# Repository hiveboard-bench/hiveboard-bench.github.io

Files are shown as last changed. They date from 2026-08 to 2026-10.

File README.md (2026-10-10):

# HiveBoard Website





This repository hosts the official project website for **HiveBoard: An Open, Modular, 3D-Printed Benchmark of Industrial Mechanisms for Robotic and Prosthetic Manipulation**.

**Live Website:** [hiveboard-bench.github.io](https://hiveboard-bench.github.io)  
**Main Project Repository:** [github.com/hiveboard-bench/HiveBoard](https://github.com/hiveboard-bench/HiveBoard)

## Website Purpose

The purpose of this website is to serve as the interactive companion and presentation portal for the HiveBoard benchmark:

- **Interactive 3D & Physics Viewer:** Allows visitors to view and interactively simulate the attachments directly in the browser using [Three.js](https://threejs.org/) and WebAssembly-powered [MuJoCo](https://mujoco.org/).
- **Attachment & Task Catalog:** Details 12 functional 3D-printed attachment designs evaluated in 13 conditions across three manipulation skill categories: *Torque*, *Precision*, and *Composed assembly*.
- **Simulation Compatibility:** Provides information and direct access to digital assets for simulators including MuJoCo, Isaac Sim (USD), and standard URDFs.
- **Experimental Results & Media:** Showcases evaluation results and video demonstrations across diverse robotic embodiments (fixed-base arms, quadruped manipulators, VR-teleoperated robots, and wearable prosthetic hands).
- **Documentation & Evaluation Protocol:** Includes the full HiveBoard documentation, contribution guides, and browser-based 65-trial evaluation runner at [`/hivedocs/`](https://hiveboard-bench.github.io/hivedocs/).

## Tech Stack

- **Bundler / Dev Server:** [Vite](https://vitejs.dev/)
- **UI Framework / Styling:** [Bulma CSS](https://bulma.io/) & Custom CSS
- **3D & Physics Rendering:** [Three.js](https://threejs.org/) & [@mujoco/mujoco](https://www.npmjs.com/package/@mujoco/mujoco)
- **Deployment:** GitHub Pages via `gh-pages`

## Getting Started

### Prerequisites

Make sure you have [Node.js](https://nodejs.org/) (version 18+ recommended) installed.

### Installation

Clone the repository and install the dependencies:

```bash
git clone https://github.com/hiveboard-bench/hiveboard-bench.github.io.git
cd hiveboard-bench.github.io
npm install
```

### Local Development

Start the local Vite development server:

```bash
npm run dev
```

Open your browser at `http://localhost:5173` (or the URL printed in your terminal).

### Build for Production

To create an optimized production build in the `dist/` directory:

```bash
npm run build
```

You can preview the built site locally with:

```bash
npm run preview
```

### Deployment

Deploy to GitHub Pages:

```bash
npm run deploy
```

## Modifying & Authoring Trajectories

The simulation viewer replays deterministic task-space trajectories (approach, grasp, actuate, release, retreat) solved with inverse kinematics and verified against MuJoCo physics. You can modify these trajectories in two ways:

### 1. Interactive Browser-Based Editor

The repository includes a live visual editor to adjust waypoints directly in 3D:

1. **Start the editor backend server:**
   ```bash
   python3 tools/traj_edit.py
   ```
2. **Start the Vite dev server (in a separate terminal):**
   ```bash
   npm run dev
   ```
3. **Open the editor in your browser:**  
   Navigate to `http://localhost:5173/sim/hiveboard-sim.html?edit=1`
4. **Interact & Save:**
   - Click and drag the keyframe beads along the motion path (or select a bead and use arrow keys to nudge coordinates).
   - The backend re-solves IK and simulates acceptance replay in real-time.
   - Click **Save** to persist waypoint offsets to `tools/traj_edits.json` and update the robot's `.traj.json` file.

### 2. Programmatic Authoring via Python

- **Task Keyframes & Logic:** Authored in [`tools/sim_trajectories.py`](tools/sim_trajectories.py) (defines Cartesian waypoints, approach directions, gripper actions, and acceptance criteria).
- **Robot Specs & Layouts:** Configured in [`tools/build-sim-assets.py`](tools/build-sim-assets.py).
- **Rebuild Assets & Trajectories:**
  ```bash
  python3 tools/build-sim-assets.py
  ```
*(This compiles MuJoCo scenes, solves IK, and runs acceptance tests across all attachments).*

### NVIDIA cuMotion for FR3 and Spot

The FR3 and Spot trajectory builders use NVIDIA's standalone cuMotion package.
It requires a supported NVIDIA GPU and a matching CUDA release. On Ubuntu 24.04
with CUDA 13, install the project-local Python environment and official NVIDIA
wheel with:

```bash
tools/install-cumotion.sh
.venv/bin/python tools/test_cumotion_integration.py
.venv/bin/python tools/test_cumotion_tasks.py
```

The installer defaults to cuMotion 1.1.0 for CUDA 13.0. For Ubuntu 22.04 with
CUDA 12.6, run `CUMOTION_CUDA_VERSION=12.6 tools/install-cumotion.sh`. NVIDIA's
binary package supports Python 3.10–3.14; the installer picks the matching
wheel for `python3`. See NVIDIA's [system requirements and installation
guide](https://nvidia-isaac.github.io/cumotion/getting_started.html#installation)
before choosing a package for another platform.

To run the planner directly, pass the robot's target joint positions. The
planner defaults the starting state to that robot's cuMotion home pose:

```bash
.venv/bin/python tools/cumotion_planner.py --robot fr3 \
  --goal -0.65 -0.04 0.64 -2.08 0.02 2.05 0.77
```

To regenerate the simulator scenes and rerun task acceptance for FR3 or Spot,
provide the HiveBoard asset checkout:

```bash
.venv/bin/python tools/build-sim-assets.py \
  --hiveboard /path/to/HiveBoard/Simulation --robot fr3
.venv/bin/python tools/build-sim-assets.py \
  --hiveboard /path/to/HiveBoard/Simulation --robot spot
```

The cuMotion Python runtime is a GPU binary and is not installed by the web
site's Node.js dependencies. The browser continues to play the generated
MuJoCo trajectories; Python cuMotion is needed only to regenerate them.

### ANYmal-D + DynaArm + Robotiq 2F-140

The `anymal` model is available in `public/sim/models/anymal.xml`, with editable
starter trajectories for the ball valve, light bulb, and circuit breaker. To start editing:

```bash
pip install mujoco numpy
python3 tools/traj_edit.py --robot anymal
# In another terminal: npm run dev
```

Open `http://localhost:5173/sim/hiveboard-sim.html?edit=1&robot=anymal`.
The initial paths are **drafts**: their contact replays do not pass task acceptance
yet. They are starting points for waypoint/joint editing, not successful demos.

To regenerate only this robot from the Isaac assets (run from this directory):

```bash
pip install mujoco numpy usd-core fast-simplification
python3 tools/build-sim-assets.py --robot anymal \
  --isaaclab-repo ../.. --hiveboard ../HiveBoard/Simulation
python3 tools/check-anymal.py --isaaclab-repo ../..
```

`--isaaclab-repo` points to the `isaaclab-hiveboard` checkout. NVIDIA USD layers
are downloaded into `.cache/anymal-usd` on the first build; `--usd-cache` can
select an existing download. Viewing and editing the generated model needs no
USD installation or NVIDIA connection. Full asset builds also include ANYmal.
The local `assets/anymal/usd/dynaarm.usd` and its `configuration/` layers must
exist before rebuilding. These are ignored generated files in the Isaac repo:
spawning ANYmal there once creates them from the committed DynaArm URDF and
the `duatic_dynaarm` submodule. Regenerate them after changing that URDF.

The conversion uses the ANYmal-D USD, the local corydoras12 DynaArm USD/URDF,
and the Isaac Robotiq 2F-140 USD. It preserves the six arm joint names and limits,
the mount at `(0, 0, 0.12)` with 180° yaw, and the identity flange-to-palm weld.
The TCP is 0.20 m along the palm's +Z, with the website's +Z approach convention
(Isaac's canonical TCP uses a different orientation offset). Gripper commands
are radians: 0 open, 0.7 closed, with the inner fingers following the drive at -1.

The base and legs are fixed in the Isaac standing pose, as required by the
existing arm trajectory editor. MuJoCo uses position servos, gravity compensation,
convex mesh contacts and explicit four-bar loop/mimic constraints. Robot self
collisions are disabled, matching the Isaac assembly. Visual meshes are simplified
and texture maps replaced with solid colors. This is a manipulation-authoring
model, not a locomotion model or a dynamics-equivalent PhysX conversion.

See [the converter](tools/anymal_model.py) for asset URLs and
[the validation script](tools/check-anymal.py) for URDF forward-kinematics,
gripper linkage, editor and packaging checks. The generated model was also
checked with the bundled MuJoCo WASM 3.11.0 runtime.

## Repository Structure

```text
├── assets-src/      # Source assets and 3D models
├── docs/            # VitePress documentation and evaluation runner
├── public/          # Static assets served directly (textures, models, videos)
├── src/             # Frontend source scripts and utilities
├── tools/           # Python helper scripts for model compression and asset optimization
├── index.html       # Main HTML page and presentation layout
├── viewer.js        # MuJoCo WebAssembly and Three.js 3D interactive viewer logic
├── style.css        # Website styling and responsive design rules
└── package.json     # Node.js dependencies and scripts
```

## Open Calls for Contributions

We invite laboratories, individual researchers, and teams to contribute manipulation datasets or develop functional attachments for benchmark extensions:

- **[Learning Datasets](https://hiveboard-bench.github.io/hivedocs/contribute/evaluations)**: Robot demonstrations and rollouts with synchronized states, actions, camera observations, and task outcomes. Use [DataHive](https://hiveboard-bench.github.io/hivedocs/guides/datahive) or agreed custom formats.
- **[Activities of Daily Living (ADL)](https://hiveboard-bench.github.io/hivedocs/contribute/adl)**: Functional mechanisms representing everyday manipulation tasks with repeatable initial states and observable success conditions.
- **[Bimanual Manipulation](https://hiveboard-bench.github.io/hivedocs/contribute/bimanual)**: Attachments requiring coordinated manipulation by two hands or end-effectors.

Substantial accepted datasets and functional attachment packages can establish eligibility for co-authorship on future papers. See the [submission requirements and credit policy](https://hiveboard-bench.github.io/hivedocs/contribute/requirements). Contact [Ricardo V. Godoy](mailto:ricardo.godoy@usp.br) before starting design or collection.

## Citation

If you find HiveBoard useful in your research, please cite:

```bibtex
@article{godoy2024hiveboard,
  title     = {HiveBoard: An Open, Modular, 3D-Printed Benchmark of Industrial Mechanisms for Robotic and Prosthetic Manipulation},
  author    = {Godoy, Ricardo V. and de Souza, Enzo F. and Angarola, Matheus P. and de Lange, Rudy De-Xin and Negri, Juliano and Marsicano, Jo{\~a}o A. and Aléssio, João H. and van Halst, Victor and Vijayan, Aravind Elanjimattathil and Capezzuto, Gianluca and Tommaselli, Felipe and Milazzo, Giuseppe and Ramírez Sánchez, Amy M. and Affonso, Francisco and Baptista, Rafael R. and van Berge, Meiko A. and Chowdhary, Girish and Bezerra, Ranulfo and Lahr, Gustavo J. G. and Gerez, Lucas Ferrari and Bicchi, Antonio and Becker, Marcelo},
  journal   = {arXiv preprint},
  year      = {2024}
}
```

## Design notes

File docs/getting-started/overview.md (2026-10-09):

# Benchmark overview

HiveBoard evaluates manipulation of mechanisms with constrained motion. A platform may need to rotate a valve about a fixed axis, keep a screw engaged with its thread, align and insert a key, or complete a sequence of dependent actions.

<figure class="doc-image">
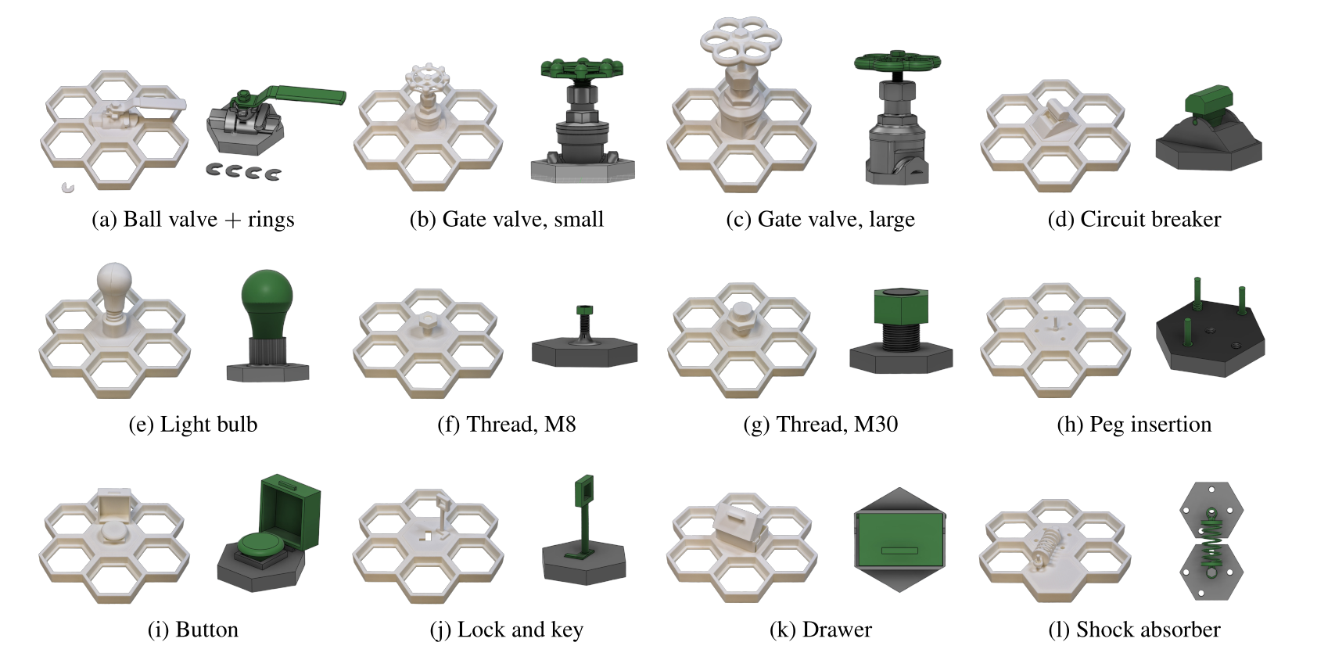
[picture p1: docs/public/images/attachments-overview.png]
HiveBoard attachments grouped by manipulation category
  
  <figcaption>The HiveBoard attachments shown on the honeycomb base and as isolated mechanisms.</figcaption>
</figure>

## Hardware and platform support

### Reproducible hardware

All structural and functional parts are designed for consumer-grade fused-deposition modelling using PLA. The shared press-fit geometry allows laboratories to reproduce the same board without a specialized fixture.

### Modular tasks

HiveBoard has 12 attachment designs evaluated in 13 conditions. The ball valve is evaluated without and with a friction ring, giving two conditions for the same attachment design.

The seven-cell honeycomb base accepts interchangeable attachments. Attachments can be swapped without changing the base, and new tasks can reuse the same mounting interface.

### Embodiment-independent evaluation

The protocol treats a platform as an end-effector plus the system that positions and commands it. This keeps the benchmark applicable to fixed-base manipulators, quadruped manipulators, wearable devices, prosthetic hands, and exoskeletons.

The physical validation covers six platforms, including Alter-Ego with a Pisa/IIT SoftHand. Alter-Ego uses Cartesian teleoperation through a VR headset with the board mounted horizontally. See the [platform results and demonstration videos](https://hiveboard-bench.github.io/#Results).

### Simulation models

The repository includes articulated assets with visual and collision meshes, joint limits, and nominal physical properties. These assets support inspection and integration in common robotics simulators; a separate repository contains the Isaac Lab implementation.

## Task categories {#task-families}

| Category | What it tests | Attachments |
|---|---|---|
| Torque | Rotational manipulation and force transmission | Ball valve; Ball valve + ring; Gate valve (small); Gate valve (large); Circuit breaker |
| Precision | Alignment, threading, insertion, and controlled rotation | Light bulb; Thread (M8); Thread (M30); Peg insertion |
| Composed assembly | Ordered sequences with stage-wise progress | Button; Lock and key; Drawer; Shock absorber |

## What the benchmark reports

For each attachment, the protocol records:

- task outcome and completion time;
- attempts and regrasps;
- prehensile or non-prehensile strategy;
- last completed stage for composed assembly tasks; and
- one dominant failure cause for unsuccessful trials.

HiveBoard is intended to characterize task performance and failure modes. The validation protocol does not, by itself, define a universal ranking of platforms or control interfaces.

## Repository files

The current files are maintained in the [HiveBoard parts and protocol repository](https://github.com/hiveboard-bench/HiveBoard):

- `STL/` — printable parts;
- `CAD/` — editable source geometry;
- `Simulation/` — URDF and USD assets;
- `Documentation/` — protocol and trial templates.

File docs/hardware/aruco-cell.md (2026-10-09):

---
description: Print and assemble the HiveBoard ArUco cell for board localization, physical-to-simulation alignment, and dataset collection.
---

# ArUco cell

The ArUco cell provides a visual reference for locating HiveBoard in camera images. Its estimated pose can be used to place the board in a robot coordinate frame or align a simulated scene with a physical setup.

The cell is an optional accessory. Benchmark evaluations still contain **13 conditions with five trials each**.

<figure class="doc-image">
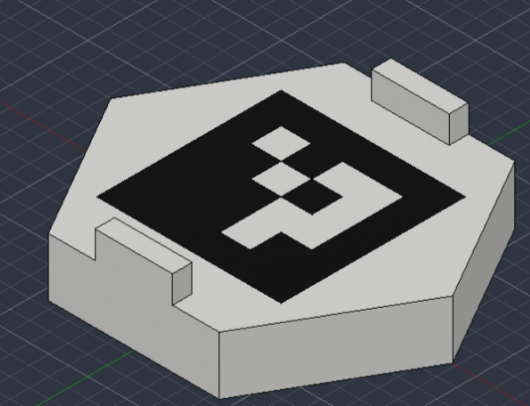
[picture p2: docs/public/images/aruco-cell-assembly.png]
CAD view of the ArUco cell, with a white hexagonal base and black marker insert
  
  <figcaption>Assembly model. The white base and black insert are printed separately and fitted together.</figcaption>
</figure>

## Files and materials

Download the files from [`CAD/ArUco Cell/`](https://github.com/hiveboard-bench/HiveBoard/tree/main/CAD/ArUco%20Cell).

| File | Purpose | Filament |
|---|---|---|
| `aruco_cell_base_white.obj` | Hexagonal base and white marker regions | White PLA |
| `aruco_cell_marker_black.obj` | Black marker insert | Black PLA |
| `aruco_cell_assembly.obj` | Reference model showing both parts in position | — |

Keep each OBJ beside its matching MTL file. MTL files specify display colors. Select the filament separately in the slicer. Print the base and insert as separate parts.

## Dimensions and import scale

The OBJ coordinates correspond to centimetres. Set the import units or scale explicitly.

| Quantity | Value |
|---|---|
| Overall width | 88.1 mm |
| Assembly bounding box | 88.1 × 76.297 × 22.0 mm |
| Nominal outer black square | 47.505 mm per side |
| Import into a millimetre-based application | Multiply coordinates by 10 |
| Import into a metre-based simulator | Multiply coordinates by 0.01 |

Apply the same scale to both parts. Confirm the assembled width before printing. For pose estimation, measure the printed marker from the outer edges of its black square. Use that measured side length in the detector.

## Print and assemble

1. Import the base and insert with the scale specified above.
2. Print the base in white PLA and the insert in black PLA. Use the [PLA printing settings](/hardware/printing#printer-requirements) as a starting point.
3. Remove stringing and excess material from the mating surfaces.
4. Fit the insert into the base, following the assembly model. Check that it is fully seated and the marker face is complete.
5. For permanent assembly, apply a small amount of PLA-compatible adhesive to the mating surfaces. Keep adhesive off the marker face and allow it to cure.
6. Seat the cell in the honeycomb base. Choose a position visible to the camera that leaves the required task cells available and the robot's approach clear.

Check that the cell remains fixed during manipulation. Recheck its pose relative to the board after moving or reseating it.

## Marker and camera configuration

| Parameter | Setting |
|---|---|
| OpenCV dictionary | `DICT_4X4_50` |
| Marker ID | `0` |
| Marker side length | Measured outer black-square side, in the units used for pose estimation |

The marker was created with [chev.me/arucogen](https://chev.me/arucogen/) using **4×4 (50, 100, 250, 1000)** and **ID 0**. This ID has the same pattern in the four standard OpenCV 4×4 dictionaries. Use `DICT_4X4_50` for a consistent detector configuration.

Calibrate the camera at the resolution used for detection and retain its intrinsic parameters and distortion coefficients. Verify detection of ID 0 on the printed cell at the intended working distance and viewing angles. Check that the marker remains visible under the experiment's lighting conditions.

Pose estimation also requires the marker's position and orientation relative to the chosen board frame. To express the board pose in robot coordinates, obtain the camera pose in that coordinate frame. For a moving camera, use the camera pose corresponding to the image timestamp.

See the [OpenCV ArUco documentation](https://docs.opencv.org/4.x/d5/dae/tutorial_aruco_detection.html) for detection and pose estimation.

## Physical-to-simulation alignment

Import the assembly mesh with the correct scale and place it relative to the same board frame used in the physical setup. Use the measured marker-to-board transform when converting a detected marker pose into a board pose.

Check the resulting alignment at known points on the board before using it for robot motion or comparing trajectories. Record the coordinate-frame conventions, camera calibration, and marker-to-board transform. The cell provides a reference for geometric alignment. Physical parameter identification is described in [Simulation assets](/simulation/assets#physical-parameters).

## Record with a dataset

When using the cell during [DataHive collection](/guides/datahive), retain:

- the camera images and timestamps used for detection;
- camera intrinsics, distortion coefficients, and camera-to-robot calibration when used;
- the dictionary, marker ID, and measured marker side length;
- the marker-to-board transform and coordinate-frame definitions;
- any estimated poses, with their timestamps and detection failures.

Keep these calibration records with the session metadata. Agree on supplemental files with the organizers if they fall outside the current DataHive episode format. Installing DataHive does not configure marker detection or board-pose estimation.

For benchmark evaluations, record the localization method in the platform description and continue to record each trial with an external camera.

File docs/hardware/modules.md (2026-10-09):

# Attachment reference {#module-reference}

HiveBoard has 12 attachment designs evaluated in 13 conditions. The ball valve is evaluated without and with a friction ring, giving two conditions for the same attachment design. The conditions belong to three task categories.

See [Terminology](/reference/terminology) for the task names, trial IDs, and names used in older files.

For operating instructions, use [How to perform each task](/benchmark/tasks). It includes the starting state and reset for each mechanism, with a [step-by-step shock absorber task](/benchmark/tasks#shock-absorber).

<figure class="doc-image">
  Overview of the twelve HiveBoard attachment designs
  <figcaption>Attachment overview. Each mechanism uses the shared honeycomb mounting interface.</figcaption>
</figure>

## Torque-based tasks {#torque-tasks}

| ID | Attachment | Required outcome | Timeout |
|---|---|---|---:|
| `valve_ball` | Ball valve | Rotate the handle 90° from closed to open | 60 s |
| `valve_ball_ring` | Ball valve + ring | Rotate the handle 90° with the ring fitted | 90 s |
| `valve_gate_small` | Gate valve (small) | Complete one full turn of the stem | 90 s |
| `valve_gate_large` | Gate valve (large) | Complete one full turn of the stem | 120 s |
| `circuit_breaker` | Circuit breaker | Move the toggle to the other state and hold it | 60 s |

The gate-valve criterion is one complete stem rotation, not full travel. The number of turns required for full travel can vary with the printed thread pitch.

## Precision-based tasks {#precision-tasks}

| ID | Attachment | Required outcome | Timeout |
|---|---|---|---:|
| `light_bulb` | Light bulb | Thread the bulb until it is seated | 120 s |
| `thread_m8` | Thread (M8) | Thread the bolt along the available length | 120 s |
| `thread_m30` | Thread (M30) | Thread the bolt along the available length | 120 s |
| `peg_insertion` | Peg insertion | Thread the free peg into the empty socket until seated | 120 s |

The peg task uses a threaded 8 mm pin. It is not a clearance-fit insertion task.

## Composed assembly tasks

These tasks are scored by the last completed stage as well as by full success.

| ID | Attachment | Stage 1 | Stage 2 | Stage 3 | Timeout |
|---|---|---|---|---|---:|
| `button` | Button | Open cover | Press button | — | 60 s |
| `lock` | Lock and key | Grasp key | Insert key vertically | Rotate to unlock | 180 s |
| `drawer` | Drawer | Grasp handle | Pull open | Push closed | 120 s |
| `shock_absorber` | Shock absorber | Grasp loose part | Align its hole with the pin | Insert part fully onto pin | 180 s |

Record `0` when no stage is completed. A full success reaches the final stage listed for the attachment.

## Optional accessory

The [ArUco cell](/hardware/aruco-cell) provides a visual reference for board localization and physical-to-simulation alignment. It adds no scored task or evaluation condition.

## Printable files

The attachment folders and their components are available under [`STL/`](https://github.com/hiveboard-bench/HiveBoard/tree/main/STL). The same high-level folder names are used under `CAD/` and `Simulation/` where the corresponding assets are available.

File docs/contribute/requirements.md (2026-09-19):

---
description: Required files, validation evidence, and contributor credit for the HiveBoard attachment calls.
---

# Contribution requirements and credit

These requirements apply to the [ADL](/contribute/adl) and [bimanual manipulation](/contribute/bimanual) calls. Discuss the proposal with the authors before starting detailed design. Use the [attachment guide](/guides/new-attachment) for technical integration.

## Required files and evidence

A complete attachment contribution must let another laboratory fabricate, assemble, simulate, and operate the mechanism.

| Component | Required material |
|---|---|
| Editable design | Native CAD source and a neutral exchange format such as STEP; dimensions and mounting geometry |
| Printable parts | STL files for every printed component, with units, quantities, orientation, and printing settings |
| Assembly | Bill of materials, specifications for non-printed parts, illustrated assembly instructions, and an assembled-prototype photograph |
| Simulation | Articulated URDF and/or USD model in the format agreed with the authors; all referenced visual and collision meshes; joint axes, limits, initial values, and documented physical parameters |
| Simulation check | Loading instructions, software versions, and a runnable script or reproducible procedure that exercises the moving parts |
| Task definition | Initial state, action sequence, success criterion, timeout, intermediate stages where needed, failure conditions, and reset procedure |
| Physical validation | External-camera video showing mounting, full mechanism operation, successful task execution, and reset; both hands visible for a bimanual task |
| Trial example | At least one completed example trial record, identifying the mechanism version, performer or platform, and any known limitations |
| Attribution and provenance | Contributor names and roles, sources of reused material, and the existing licenses or permissions for those materials |

Identify measured physical parameters separately from nominal simulation values. A render alone does not demonstrate a functional attachment. Label human demonstrations and robot trials accurately; discuss the available validation platform with the authors during the proposal stage.

## Submission and review

1. **Propose the task.** Send the idea and sketch to [ricardo.godoy@usp.br](mailto:ricardo.godoy@usp.br). The authors check scope, overlap, feasibility, and the intended contribution.
2. **Agree on the deliverables.** Confirm mounting, simulation format, validation evidence, and applicable contribution licenses before preparing the final package.
3. **Build and validate.** Complete the files above and document any unresolved limitations.
4. **Submit for review.** Send a repository or file-package link to the authors. They will coordinate the pull request to the appropriate HiveBoard repository. Include a short file index and the contributor roles.
5. **Address review comments.** Acceptance depends on function, reproducibility, task relevance, and file completeness. The maintainers coordinate integration into a versioned extension.

The example record validates the proposed task description; it does not constitute a complete benchmark evaluation. Evaluations of the current benchmark still require **all 13 conditions and five trials per condition**.

## Authorship and acknowledgments

Anyone who contributes **at least one accepted, functional attachment with all required files and validation evidence** may be eligible for authorship on future HiveBoard papers that use and report that contribution.

Authorship is assessed for each paper. Eligible contributors should also participate in drafting or substantive revision of the paper, approve its final version, and take responsibility for their contribution. Attachment acceptance does not guarantee authorship on every future HiveBoard paper or establish author order. The authors will discuss the expected role when planning the relevant paper.

Smaller contributions, such as design suggestions, documentation corrections, or limited testing, may be credited in the acknowledgments with the contributor's consent. These contributions are also welcome. Keep a record of each person's work so credit reflects the contribution made.

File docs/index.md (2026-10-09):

# HiveBoard

HiveBoard is an open, modular, fully 3D-printable benchmark for manipulation of functional mechanisms. Its interchangeable attachments cover rotational, threaded, insertion, linear, and multi-stage tasks. The same board and protocol can be used with robot grippers, dexterous hands, teleoperated systems, and worn prosthetic hands.

The physical validation covers six platforms, including Alter-Ego with a Pisa/IIT SoftHand. For the paper, demonstration videos, and per-condition results, see the [HiveBoard project website](https://hiveboard-bench.github.io).

## Documentation

**Running an evaluation?** Start with [How to perform each task](/benchmark/tasks) for initial states, actions, success criteria, timeouts, and resets. For example, see the [shock absorber instructions](/benchmark/tasks#shock-absorber).

- [Benchmark overview](/getting-started/overview)
- [Getting started](/getting-started/quick-start)
- [3D printing](/hardware/printing)
- [Assembly and mounting](/hardware/assembly)
- [Attachment reference](/hardware/modules)
- [Evaluation Runner](/benchmark/evaluation-runner)
- [Evaluation protocol](/benchmark/protocol)
- [Data collection with DataHive](/guides/datahive)
- [Simulation assets](/simulation/assets)

The printable parts, CAD models, articulated assets, protocol, and trial templates are maintained in the [HiveBoard repository](https://github.com/hiveboard-bench/HiveBoard). The Isaac Lab environments are maintained in a [separate repository](https://github.com/hiveboard-bench/isaaclab-hiveboard).

## Open calls for contributions

We invite laboratories and individual researchers to [contribute datasets for learning-based manipulation](/contribute/evaluations), including robot states, actions, camera observations, timestamps, calibration, and task outcomes. There is no fixed episode count; larger collections of demonstrations and rollouts are encouraged.

Use [DataHive](/guides/datahive) to collect, annotate, validate, and upload episodes. We encourage labs running a benchmark evaluation to record learning data during the same trials when their system supports it.

We welcome functional attachments for [activities of daily living](/contribute/adl) and [bimanual manipulation](/contribute/bimanual). Contact the authors before starting a design to check its suitability and avoid duplicating work.

Contributors who deliver at least one accepted, functional attachment with the complete files and validation evidence may be eligible for authorship on future papers that use the contribution. Smaller contributions may be acknowledged. See the [requirements and credit policy](/contribute/requirements).

## Citation

If you use HiveBoard in your research, please cite the project paper:

```bibtex
@article{hiveboard2026,
  title   = {HiveBoard: An Open, Modular, 3D-Printed Benchmark of Industrial
             Mechanisms for Robotic and Prosthetic Manipulation},
  author  = {Godoy, Ricardo V. and de Souza, Enzo F. and Angarola, Matheus P. and
             de Lange, Rudy De-Xin and Negri, Juliano and Marsicano, Joao A. and others},
  journal = {Under review},
  year    = {2026},
  url     = {https://github.com/hiveboard-bench/HiveBoard}
}
```

The citation metadata may change while the paper is under review. See the [citation page](/reference/citation) before preparing a publication.

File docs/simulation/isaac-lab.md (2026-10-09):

# Isaac Lab integration

The [`hiveboard-bench/isaaclab-hiveboard`](https://github.com/hiveboard-bench/isaaclab-hiveboard) repository provides HiveBoard environments for Spot with arm, Franka FR3, and ANYmal with DynaArm. The current implementation uses Isaac Lab with **Newton MJWarp**. The standard simulation and recording workflows run without Isaac Sim.

This guide follows `master` at commit [`1d7a042`](https://github.com/hiveboard-bench/isaaclab-hiveboard/commit/1d7a0421154af19883eadc0e5d3b12eda2cb2a00), checked on 8 October 2026. For command editing, episode recording, and the separate learning repository, see [Simulation workflows](/simulation/workflows).

## Simulation videos

Four examples from the [Isaac Lab video gallery](https://hiveboard-bench.github.io/#Videos), featuring two tasks each with ANYmal D and Franka FR3:

<div class="simulation-video-grid">
  <figure>
    <video controls playsinline preload="none" poster="/images/anymal_d_isaac_ball_valve.webp" aria-label="ANYmal D operating a ball valve">
      <source src="https://github.com/hiveboard-bench/hiveboard-bench.github.io/releases/download/v1.0-v1.0-videos/anymal_d_isaac_ball_valve.mp4" type="video/mp4">
    </video>
    <figcaption>ANYmal D · Ball valve</figcaption>
  </figure>
  <figure>
    <video controls playsinline preload="none" poster="/images/anymal_d_isaac_button.webp" aria-label="ANYmal D pressing a button">
      <source src="https://github.com/hiveboard-bench/hiveboard-bench.github.io/releases/download/v1.0-v1.0-videos/anymal_d_isaac_button.mp4" type="video/mp4">
    </video>
    <figcaption>ANYmal D · Button</figcaption>
  </figure>
  <figure>
    <video controls playsinline preload="none" poster="/images/fr3_isaac_circuit.webp" aria-label="Franka FR3 operating a circuit breaker">
      <source src="https://github.com/hiveboard-bench/hiveboard-bench.github.io/releases/download/v1.0-v1.0-videos/fr3_isaac_circuit.mp4" type="video/mp4">
    </video>
    <figcaption>Franka FR3 · Circuit breaker</figcaption>
  </figure>
  <figure>
    <video controls playsinline preload="none" poster="/images/fr3_isaac_big_gate_valve.webp" aria-label="Franka FR3 operating a large gate valve">
      <source src="https://github.com/hiveboard-bench/hiveboard-bench.github.io/releases/download/v1.0-v1.0-videos/fr3_isaac_big_gate_valve.mp4" type="video/mp4">
    </video>
    <figcaption>Franka FR3 · Gate valve (large)</figcaption>
  </figure>
</div>

## Simulation videos

Four examples from the [Isaac Lab video gallery](https://hiveboard-bench.github.io/#Videos), featuring two tasks each with ANYmal D and Franka FR3:

<div class="simulation-video-grid">
  <figure>
    <video controls playsinline preload="none" poster="/images/anymal_d_isaac_ball_valve.webp" aria-label="ANYmal D operating a ball valve">
      <source src="https://github.com/hiveboard-bench/hiveboard-bench.github.io/releases/download/v1.0-v1.0-videos/anymal_d_isaac_ball_valve.mp4" type="video/mp4">
    </video>
    <figcaption>ANYmal D · Ball valve</figcaption>
  </figure>
  <figure>
    <video controls playsinline preload="none" poster="/images/anymal_d_isaac_button.webp" aria-label="ANYmal D pressing a button">
      <source src="https://github.com/hiveboard-bench/hiveboard-bench.github.io/releases/download/v1.0-v1.0-videos/anymal_d_isaac_button.mp4" type="video/mp4">
    </video>
    <figcaption>ANYmal D · Button</figcaption>
  </figure>
  <figure>
    <video controls playsinline preload="none" poster="/images/fr3_isaac_circuit.webp" aria-label="Franka FR3 operating a circuit breaker">
      <source src="https://github.com/hiveboard-bench/hiveboard-bench.github.io/releases/download/v1.0-v1.0-videos/fr3_isaac_circuit.mp4" type="video/mp4">
    </video>
    <figcaption>Franka FR3 · Circuit breaker</figcaption>
  </figure>
  <figure>
    <video controls playsinline preload="none" poster="/images/fr3_isaac_big_gate_valve.webp" aria-label="Franka FR3 operating a large gate valve">
      <source src="https://github.com/hiveboard-bench/hiveboard-bench.github.io/releases/download/v1.0-v1.0-videos/fr3_isaac_big_gate_valve.mp4" type="video/mp4">
    </video>
    <figcaption>Franka FR3 · Gate valve (large)</figcaption>
  </figure>
</div>

## Requirements

Use the dependencies specified by the repository's [`pyproject.toml`](https://github.com/hiveboard-bench/isaaclab-hiveboard/blob/1d7a0421154af19883eadc0e5d3b12eda2cb2a00/pyproject.toml) and Git submodules.

| Component | Current configuration |
|---|---|
| Python | 3.12 |
| Isaac Lab | Source checkout in `dependencies/IsaacLab`, pinned to `78b12aed` |
| Physics | Newton 1.6.1 with the `newton_mjwarp` preset |
| Package manager | `uv` |
| Motion planning | cuRobo from `dependencies/curobo`, included in the project dependencies |
| Video encoding | `ffmpeg` and `ffprobe` on `PATH` |
| Task editor | Web browser for the local Viser interface |

The GPU workflows use CUDA dependencies. RTX video rendering requires compatible NVIDIA hardware. The player also accepts `--device cpu` for CPU runs, subject to the selected task and planner.

## Installation

Clone the repository and its pinned submodules:

```bash
git clone --branch master --recurse-submodules https://github.com/hiveboard-bench/isaaclab-hiveboard.git
cd isaaclab-hiveboard
uv sync --python 3.12
```

After updating an existing checkout, synchronize its dependencies:

```bash
git submodule update --init --recursive
uv sync --python 3.12
```

Run commands from the repository root through `uv run`. Keep the Isaac Lab submodule at the commit recorded by the HiveBoard checkout.

### Generate the Newton assets

The generated Newton USD files are build outputs and must be created on a fresh clone. Initializing the asset submodules alone does not generate them.

First, check which outputs are missing:

```bash
uv run python scripts/generate_newton_usd.py --verify-only
```

A failed check is expected before generation. Install [urdf-usd-converter](https://github.com/newton-physics/urdf-usd-converter) in a separate Python environment, then pass that environment's Python executable to the generator:

```bash
uv venv --python 3.12 .venv-uuc
uv pip install --python .venv-uuc/bin/python urdf-usd-converter
uv run python scripts/generate_newton_usd.py \
  --uuc-python .venv-uuc/bin/python
uv run python scripts/generate_newton_usd.py --verify-only
```

Record the converter version with the experiment. The generator also accepts `--assets` to rebuild one mechanism, for example `--assets lamp`.

After updating an existing checkout, regenerate the key and drawer assets. The key now uses separate key and lock USDs; the drawer uses a fixed housing and a free box guided by contact. Regeneration also applies the revised collision geometry and contact materials:

```bash
uv run python scripts/generate_newton_usd.py \
  --assets key --uuc-python .venv-uuc/bin/python
uv run python scripts/generate_newton_usd.py \
  --assets drawer --uuc-python .venv-uuc/bin/python
uv run python scripts/generate_newton_usd.py --verify-only
```

For ANYmal, generate and verify the robot assembly as well:

```bash
uv run python scripts/generate_anymal_newton_usd.py
uv run python scripts/generate_anymal_newton_usd.py --verify-only
```

The ANYmal generator downloads robot and gripper assets when they are absent, so its first run requires internet access.

## Heuristic task status {#available-tasks}

Task IDs have the form `Isaac-HiveBoard-<Robot>-<Tool>-v0`. Robot tokens are case-sensitive: `Spot`, `Franka`, and `Anymal`.

The table reports the heuristic status given in the [simulation README at commit `1d7a042`](https://github.com/hiveboard-bench/isaaclab-hiveboard/blob/1d7a0421154af19883eadc0e5d3b12eda2cb2a00/README.md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).

**✓**: working heuristic reported by the maintainers. **✗**: no working heuristic currently reported. All listed robot–task combinations have registered environments. The symbols describe the supplied heuristic controllers.

| Benchmark task | Tool token | Spot | Franka FR3 | ANYmal |
|---|---|:---:|:---:|:---:|
| Ball valve | `BallValve` | ✓ | ✓ | ✓ |
| Gate valve (small) | `SmallValve` | ✓ | ✓ | ✓ |
| Gate valve (large) | `HighTorqueValve` | ✓ | ✓ | ✓ |
| Circuit breaker | `CircuitBreaker` | ✓ | ✓ | ✓ |
| Button | `Button` | ✓ | ✓ | ✓ |
| Lock and key | `Key` | ✓ | ✓ | ✓ |
| Drawer | `Drawer` | ✗ | ✓ | ✓ |
| Thread (M8) | `M8Thread` | ✗ | ✓ | ✓ |
| Thread (M30) | `M30Thread` | ✗ | ✓ | ✓ |
| Peg insertion | `PegInsertion` | ✗ | ✗ | ✗ |
| Shock absorber | `ShockAbsorber` | ✗ | ✗ | ✗ |
| Light bulb | `Lamp` | ✓ | ✓ | ✓ |

These statuses apply to the supplied task configurations. They do not quantify success rates across randomized resets. For benchmark evaluations, check the configured motion and success condition against [How to perform each task](/benchmark/tasks).

Each listed task has a `-Play-v0` variant, including `Lamp` for Spot, Franka, and ANYmal. For example, the Franka ball-valve play environment is `Isaac-HiveBoard-Franka-BallValve-Play-v0`. The former `Franka-LeverValve` identifier is no longer registered.

List the registered environments without launching a simulation:

```bash
uv run python scripts/record_all_envs.py --all --list
uv run python scripts/record_all_envs.py --all --list --match Franka
```

The registry also includes `CuroboValve` planning examples, `BenchValve` joint-trajectory playback, and diagnostic tasks. [RL environments](/simulation/workflows#reinforcement-learning) are registered by the separate `hiveboard-rl` package. Registration alone does not establish task success or compliance with every benchmark condition. In particular, the two physical ball-valve conditions require an explicit simulation configuration and validation of their resistance.

### Lock-and-key setup

The [key scene](https://github.com/hiveboard-bench/isaaclab-hiveboard/blob/1d7a0421154af19883eadc0e5d3b12eda2cb2a00/source/isaaclab_hiveboard/isaaclab_hiveboard/tasks/scenes/key.py) starts with the key rigidly attached to the robot's hand. The supplied sequence approaches the lock, inserts the key, and turns the plug. It does not evaluate picking up a loose key or retaining it through a frictional grasp.

The [success check](https://github.com/hiveboard-bench/isaaclab-hiveboard/blob/1d7a0421154af19883eadc0e5d3b12eda2cb2a00/source/isaaclab_hiveboard/isaaclab_hiveboard/tasks/anymal/key/con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) requires the command sequence to finish and the plug angle to lie between 80° and 95°. Record the pre-held key condition with results and compare it with the [benchmark task](/benchmark/tasks).

### Drawer removal

The Franka and ANYmal tasks use a free drawer box inside a kinematic housing. The box can slide out and detach through contact dynamics. Their [removal success check](https://github.com/hiveboard-bench/isaaclab-hiveboard/blob/1d7a0421154af19883eadc0e5d3b12eda2cb2a00/source/isaaclab_hiveboard/isaaclab_hiveboard/tasks/anymal/drawer/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) requires the command sequence to finish, at least 5 cm of outward displacement, and both drawer shafts to clear the housing guides. A removed drawer may fall after release without losing success solely because its height changes.

Spot still has no working drawer heuristic reported. Its configured sliding success check differs from the removal check used by Franka and ANYmal.

### Light-bulb success condition

The [light-bulb success check](https://github.com/hiveboard-bench/isaaclab-hiveboard/blob/1d7a0421154af19883eadc0e5d3b12eda2cb2a00/source/isaaclab_hiveboard/isaaclab_hiveboard/mdp/terminations.py) requires the command sequence to finish and the bulb to reach the axial position specified by its total screw travel, with a 0.5 mm tolerance. The target is limited by the seated position.

A short command sequence can therefore succeed with the bulb only partly threaded. For the [benchmark light-bulb task](/benchmark/tasks#light-bulb-and-socket), configure the full travel and check that the bulb is seated. Retain the command setup with the reported result.

## Run an environment

Run the Spot ball-valve play environment:

```bash
uv run python scripts/play.py \
  --task Isaac-HiveBoard-Spot-BallValve-Play-v0 \
  physics=newton_mjwarp --visualizer newton
```

For the Franka circuit-breaker task with TCP tracking diagnostics:

```bash
uv run python scripts/play.py \
  --task Isaac-HiveBoard-Franka-CircuitBreaker-Play-v0 \
  physics=newton_mjwarp --visualizer newton --pose-debug
```

Run a bounded simulation without a viewer:

```bash
uv run python scripts/play.py \
  --task Isaac-HiveBoard-Spot-BallValve-Play-v0 \
  physics=newton_mjwarp --visualizer none \
  --device cuda:0 --max-steps 600 --no-dataset
```

| Option | Purpose |
|---|---|
| `--num_envs N` | Number of parallel environments |
| `--seed N` | Environment reset seed |
| `--max-steps N` | Stop after a fixed number of environment steps |
| `--duration S` | Limit the run to simulated seconds, while allowing success or failure to end it earlier |
| `--pose-debug` | Print TCP tracking errors |
| `--contact-debug` | Print contact forces for tasks with the required gripper sensors |
| `--setup FILE` | Load a saved command sequence and TCP settings |
| `--no-setup` | Use the command sequence defined in the task code |
| `--no-dataset` | Disable HDF5 episode recording |

The `--duration` option changes the handling of the task's episode time limit. Use the task configuration and [benchmark protocol](/benchmark/protocol) to set evaluation timeouts.

If `just` is installed, the repository provides shortcuts such as `just play Franka CircuitBreaker` and `just play Franka Lamp`.

## Record an example video

```bash
uv run python scripts/play.py \
  --task Isaac-HiveBoard-Spot-BallValve-Play-v0 \
  physics=newton_mjwarp --visualizer none \
  --video --video-renderer newton --max-steps 600 \
  --video-folder videos/spot-ball-valve --no-dataset
```

Use `--video-renderer rtx` for path-traced output. These Newton recording commands do not require the previous Isaac Sim `--enable_cameras` setup. The default playback frame rate is derived from the simulation timestep and control decimation.

For batch recording, saved command setups, and dataset collection, continue to [Simulation workflows](/simulation/workflows).

## Reporting simulation results

Record:

- the full simulation repository commit and `git submodule status --recursive`
- the Python environment, physics backend, renderer, and asset-converter version
- the task ID, robot, end-effector, and saved command setup
- physics timestep, control decimation, solver settings, and any contact or joint overrides
- observations, actions, reset distributions, seeds, success checks, and time limits
- the number of trials and whether control was scripted or learned.

Check the configured motion against [How to perform each task](/benchmark/tasks). Simulation success checks are specific to each environment and command setup. A benchmark evaluation requires all **13 conditions with five trials each**.

Report simulated and physical results separately. Document which effects were modeled, including friction, contact, attachment release, and component damage.

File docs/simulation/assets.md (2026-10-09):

# Simulation assets

The main HiveBoard repository includes articulated digital assets for the physical mechanisms. Use these files when integrating HiveBoard into an existing simulator or robotics stack.

Browse the [`Simulation/` directory](https://github.com/hiveboard-bench/HiveBoard/tree/main/Simulation).

## Available mechanism groups

| Folder | Mechanisms |
|---|---|
| `Button/` | Button |
| `Circuit Breaker/` | Circuit breaker |
| `Drawer/` | Drawer |
| `Honeycomb/` | Honeycomb base |
| `Key/` | Lock and key |
| `Lamp/` | Light bulb |
| `Peg Insertion/` | Peg insertion |
| `Shock Absorber/` | Shock absorber |
| `Threads/` | Thread (M8), Thread (M30) |
| `Valves/` | Ball valve, Gate valve (small), Gate valve (large) |

Folder names are retained for compatibility. The [terminology reference](/reference/terminology) maps older names to the task names used in the paper.

## Model contents

Depending on the mechanism, the simulation package provides:

- visual meshes
- collision meshes
- revolute, continuous, and prismatic joints
- joint ranges and limits
- nominal mass and inertia
- URDF or USD exports.

Threaded motion is represented by coupled rotational and translational joints where a native helical joint is unavailable. This reproduces the advance of a threaded component while keeping the asset portable across simulators.

## URDF and USD assets

| Goal | Starting point |
|---|---|
| Load or visualize a mechanism in an existing stack | URDF or USD assets in the main repository |
| Inspect kinematics or create a custom environment | Articulated asset plus your simulator's loader |
| Run HiveBoard tasks with Isaac Lab and Newton | [Isaac Lab installation and task reference](/simulation/isaac-lab) |
| Edit commands, record episodes, or find learning workflows | [Simulation workflows](/simulation/workflows) |
| Compare simulation with the printed board | Record model commit and locally identified physical parameters |

The Isaac Lab implementation uses generated Newton USD files. Follow the [asset-generation steps](/simulation/isaac-lab#generate-the-newton-assets) after cloning the simulation repository. Its generated files are separate from the portable URDF/USD assets in the main HiveBoard repository.

## Align the physical and simulated board

Use the optional [ArUco cell](/hardware/aruco-cell) as a visual reference for board pose. The guide covers marker detection, camera calibration, and the marker-to-board transform. Its assembly mesh is provided as OBJ/MTL under `CAD/ArUco Cell/`. For a metre-based simulator, multiply the exported coordinates by 0.01 and verify the 0.0881 m overall width.

Place the mesh relative to the board using the measured transform. Check alignment at known board points before comparing physical and simulated trajectories.

## Physical parameters

The provided masses, inertias, friction values, and contact properties are nominal. They are not system-identified values for every printed instance.

Printer calibration, filament, layer orientation, surface wear, sanding, and mechanism assembly can all change physical behavior. If close sim-to-real correspondence is required:

1. print and assemble the target mechanism
2. measure its range and actuation resistance
3. identify the relevant simulation parameters
4. store the overrides separately from the original asset
5. report both the asset commit and the identified values.

## Validation before use

Before training or evaluation, check that:

- every referenced mesh resolves
- the rest configuration has no unintended self-intersection
- joint axes and ranges match the physical mechanism
- collision geometry is sufficiently accurate for the task
- units and scale are correct
- a full actuation cycle completes without instability.

A simulation experiment must define observations, actions, reset states, success checks, termination conditions, and evaluation seeds.

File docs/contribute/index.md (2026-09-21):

---
description: Open calls for HiveBoard learning datasets and functional attachments for activities of daily living and bimanual manipulation.
---

# Open calls for contributions

We invite laboratories, individual researchers, and teams to contribute manipulation datasets using HiveBoard or develop attachments for two benchmark extensions.

| Open call | Scope |
|---|---|
| [Learning datasets](/contribute/evaluations) | Demonstrations and robot rollouts with states, actions, camera observations, calibration, and task outcomes for learning-based methods |
| [Activities of daily living (ADL)](/contribute/adl) | Mechanisms representing everyday manipulation tasks, such as operating closures, dispensing items, or handling household objects |
| [Bimanual manipulation](/contribute/bimanual) | Tasks that require coordinated action by two hands or end-effectors |

## Contribute a learning dataset

Record robot states, executed commands, and camera streams while performing HiveBoard tasks. Include timestamps, calibration, an episode index, and a loading example. There is no fixed episode count or requirement to cover all conditions; larger collections are encouraged. Contact the organizers before collection to agree on tasks, signals, and formats. See the [dataset call](/contribute/evaluations) for requirements and direct email submission.

We recommend [DataHive](/guides/datahive) for collection, annotation, validation, and upload. Labs performing a benchmark evaluation are encouraged to record learning data during those trials; collecting a dataset remains optional.

Substantial accepted datasets may establish eligibility for authorship on future dataset papers that use the contribution. Smaller contributions may be acknowledged. See the [dataset credit policy](/contribute/evaluations#authorship-and-acknowledgments).

## Propose a new attachment {#propose-a-new-asset}

Contact [Ricardo V. Godoy](mailto:ricardo.godoy@usp.br) before starting detailed design or fabrication. Send a short task description, a sketch or reference image, and the intended call. The authors will discuss whether the idea fits the benchmark, overlaps with an existing attachment, and can be tested consistently across platforms.

An initial discussion establishes the scope; acceptance follows review of the working attachment and its files.

## What to contribute

Submit a functional physical prototype, editable CAD, printable files, an articulated simulation model, assembly instructions, task and reset definitions, and validation evidence. The [submission checklist](/contribute/requirements#required-files-and-evidence) specifies the complete package.

Contributing at least one accepted, functional attachment with the complete package can establish eligibility for authorship on future papers that use the contribution. Smaller contributions may be acknowledged. Read the [credit policy](/contribute/requirements#authorship-and-acknowledgments) before starting.

The ADL and bimanual calls concern new benchmark extensions. The learning-dataset call has no fixed episode count. Formal benchmark evaluations still require **13 conditions with five trials each, for 65 trials total**. Proposed attachments do not enter the current evaluation until a revised protocol is released.

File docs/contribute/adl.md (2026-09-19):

---
description: Contribute reproducible HiveBoard mechanisms for activities of daily living.
---

# Open call: activities of daily living

We seek functional attachments representing **activities of daily living (ADL)** for evaluation with robot grippers, dexterous hands, and prosthetic hands.

The attachment should reproduce a useful part of an everyday task, with a repeatable initial state and an observable success condition. A working closure, for example, should require the intended release motion and retain the object when closed.

## Suitable proposals

Possible directions include:

- opening and closing container lids or household latches;
- fastening and releasing buckles or clothing fasteners;
- pressing a dispenser and collecting the released item; and
- manipulating household controls with a defined sequence of motions.

These are examples to discuss with the authors, not a list of approved designs. Explain what manipulation requirement the attachment adds beyond the [existing mechanisms](/hardware/modules).

## Design requirements

- Reuse the HiveBoard mounting interface and specify the space required around the attachment.
- Define the grasping surfaces, moving parts, travel limits, and operating sequence.
- State whether the task uses one hand or two. A two-handed task can also be discussed under the [bimanual call](/contribute/bimanual).
- Make the success state visible to an external camera.
- Provide a reset procedure that another laboratory can follow without adjusting the task difficulty between trials.
- Document wear, consumables, non-printed parts, and any precautions required during use.

## Propose an attachment {#propose-an-asset}

Email [ricardo.godoy@usp.br](mailto:ricardo.godoy@usp.br?subject=HiveBoard%20ADL%20attachment%20proposal) with:

1. Your name, affiliation if applicable, and proposed attachment name.
2. The everyday task and the motions needed to complete it.
3. A sketch, reference image, or existing prototype.
4. The initial state, success condition, and reset procedure.
5. The files and physical or simulation testing you expect to provide.

**Contact the authors before starting detailed design** to check suitability and coordinate overlapping proposals. See [requirements and credit](/contribute/requirements) for the complete submission package and authorship eligibility.

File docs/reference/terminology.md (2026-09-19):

# Terminology

Use the task names from Table 2 of the HiveBoard paper in instructions, figures, result tables, and interfaces. The table below maps those names to the identifiers used in trial records.

## Task names and identifiers

| Task name | Trial identifier (`attachment_id`) | Category |
|---|---|---|
| Ball valve | `valve_ball` | Torque |
| Ball valve + ring | `valve_ball_ring` | Torque |
| Gate valve (small) | `valve_gate_small` | Torque |
| Gate valve (large) | `valve_gate_large` | Torque |
| Circuit breaker | `circuit_breaker` | Torque |
| Light bulb | `light_bulb` | Precision |
| Thread (M8) | `thread_m8` | Precision |
| Thread (M30) | `thread_m30` | Precision |
| Peg insertion | `peg_insertion` | Precision |
| Button | `button` | Composed assembly |
| Lock and key | `lock` | Composed assembly |
| Drawer | `drawer` | Composed assembly |
| Shock absorber | `shock_absorber` | Composed assembly |

HiveBoard has 12 attachment designs evaluated in 13 conditions. The ball valve is evaluated without and with a friction ring, giving two conditions for the same attachment design. Ball valve + ring is the condition with the ring fitted. Record five trials for each of the 13 conditions, including separate blocks for Ball valve and Ball valve + ring.

The category headings are **Torque-based tasks**, **Precision-based tasks**, and **Composed assembly tasks**. In tables, use **Torque**, **Precision**, and **Composed assembly**. The abbreviation “Assembly” in existing templates and the paper's Table 2 refers to Composed assembly.

## Hardware, tasks, and evaluation

| Term | Meaning |
|---|---|
| Honeycomb base | The structure into which the attachments are mounted. |
| Attachment | A physical mechanism mounted on the base, such as the drawer or a gate valve. |
| Task | The operation performed on an attachment, with a specified starting state and success criterion. |
| Condition | A scored task configuration. The two ball-valve configurations are separate conditions. |
| Trial | One recorded execution of a task, ending at success, failure, timeout, or a safety stop. |
| Platform | The end-effector and the system that positions and commands it. |
| End-effector | The gripper, hand, or other terminal device that interacts with the attachment. |
| Control interface | The interface used to command the platform. Record the control mode or policy separately where relevant. |
| Asset | A digital file or model, such as CAD geometry, a mesh, URDF, or USD. Use “attachment” for the physical mechanism. |
| Attempt | A discrete approach to the task within a trial; count from 1. Abandoning an approach and starting another adds one attempt. |
| Regrasp | A release followed by grasping the part again; count from 0. An initial grasp is not a regrasp. |
| Last completed stage | The highest completed stage of a composed assembly task, recorded as `stage_reached`; 0 means no stage was completed. |
| Dominant failure cause | The single cause recorded in `failure_cause` for an unsuccessful trial. |

## Existing names in files

Older labels and file paths may use the names below. They refer to the same attachments; descriptive details such as the button cover or the threaded peg remain part of the task instructions.

| Existing label or filename term | Task name |
|---|---|
| Ball valve with friction ring | Ball valve + ring |
| Small gate valve; Valve Gate (Small) | Gate valve (small) |
| Large gate valve; Valve Gate (Large) | Gate valve (large) |
| Light bulb socket; light bulb and socket; `Lamp/` | Light bulb |
| M8 threaded fastener; Thread M8 | Thread (M8) |
| M30 threaded fastener; Thread M30 | Thread (M30) |
| Threaded peg insertion; Peg Insertion Plate | Peg insertion |
| Covered button; Hidden Push Button | Button |
| `Key/` | Lock and key |
| Sliding Drawer; `box` in image/video filenames | Drawer |
| `spring` in image/video filenames | Shock absorber |

Keep existing identifiers, paths, and data fields unchanged. For example, `lock` remains the trial identifier for Lock and key, `light_bulb` remains the identifier for Light bulb, and `control_method` remains the runner's stored field for the control interface. The CSV outcome `fail` is displayed as “Failure” in the runner.

Thread (M14) is available in the 3D viewer but is not one of the 13 scored conditions.

See [How to perform each task](/benchmark/tasks) for operating instructions and [Trial logging](/benchmark/logging) for counting conventions.

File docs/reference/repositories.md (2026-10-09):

# Repository map

HiveBoard maintains separate repositories for benchmark assets, simulation, policy learning, data collection, and the website.

| Repository | Role | Use it for |
|---|---|---|
| [`hiveboard-bench/HiveBoard`](https://github.com/hiveboard-bench/HiveBoard) | Benchmark assets | STL, CAD, URDF/USD, protocol, and trial templates |
| [`hiveboard-bench/isaaclab-hiveboard`](https://github.com/hiveboard-bench/isaaclab-hiveboard) | Isaac Lab implementation | Environments, task configuration, scripted controllers, and simulation recording |
| [`hiveboard-bench/hiveboard-rl`](https://github.com/hiveboard-bench/hiveboard-rl) | Policy learning | Reinforcement and imitation learning using a pinned Isaac Lab integration submodule |
| [`hiveboard-bench/DataHive`](https://github.com/hiveboard-bench/DataHive) | Data collection toolkit | Recording integration, local Runner, episode annotation and validation, and Hugging Face upload; start with the [DataHive guide](/guides/datahive) |
| [`hiveboard-bench/fr3_datahive`](https://github.com/hiveboard-bench/fr3_datahive) | Reference integration | Franka Research 3 example integration and Docker environment for DataHive |
| [`hiveboard-bench/hiveboard-bench.github.io`](https://github.com/hiveboard-bench/hiveboard-bench.github.io) | Project website and documentation | Paper presentation, videos, results, interactive viewer, and `docs/` with the documentation and Evaluation Runner |

The earlier [`ricardovgodoy/hiveboard-docs`](https://github.com/ricardovgodoy/hiveboard-docs) prototype has been superseded by `docs/` in the project website repository.

## Source files

To avoid conflicting instructions:

- physical geometry and the trial protocol belong to the main HiveBoard repository;
- executable Isaac Lab details belong to the Isaac Lab repository;
- policy training, expert banks, and learned-policy evaluation belong to `hiveboard-rl`;
- DataHive's episode format, recording API, and collection tools belong to the DataHive repository;
- the Franka Research 3 reference integration belongs to the `fr3_datahive` repository;
- the project website presents the research; and
- this repository contains the documentation and evaluation runner.

The documentation links to the corresponding source files in each repository.

## Version an experiment

Record a release tag when available. Otherwise record a full commit hash for every repository used. A complete experiment identifier may therefore include:

```text
HiveBoard assets: <release or commit>
Isaac Lab integration: <release or commit>
HiveBoard RL (if used): <release or commit, plus core submodule commit>
DataHive (if used): <package version or commit>
Documentation: <release or commit>
```

Avoid reporting only `main`, since its content can change after the experiment.

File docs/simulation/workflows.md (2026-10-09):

# Simulation workflows

These workflows use [the Newton-based Isaac Lab installation](/simulation/isaac-lab), checked at simulation commit [`1d7a042`](https://github.com/hiveboard-bench/isaaclab-hiveboard/commit/1d7a0421154af19883eadc0e5d3b12eda2cb2a00). Complete the dependency installation and USD generation first. Run commands from the simulation repository root.

## Edit a task's command sequence

The Viser editor lets you adjust target poses, rotation axes, screw travel, gripper commands, and the tool center point (TCP).

```bash
uv run python scripts/command_edit.py \
  --task Isaac-HiveBoard-Franka-BallValve-Play-v0 \
  --port 9080
```

Open `http://localhost:9080` in a browser on the same computer.

1. Select a command and adjust its position, orientation, or reference frame.
2. Set motion speeds, tolerances, gripper state, and hold time as needed.
3. Check the TCP offset relative to the end-effector body.
4. Preview the sequence and inspect the inverse-kinematics residuals.
5. Click **Save setup**.
6. Run the saved sequence with physics before collecting data.

The editor preview is kinematic. Contact forces, object motion, collisions, and cuRobo plans must be checked in the simulation run.

### Saved setups

By default, the editor and player look for `configs/<task>.json`. A `-Play-v0` task falls back to its base task's file when it has no file of its own. An explicit `--setup FILE` selects a different file.

The editor saves to the loaded file, or to `configs/<task>.json` for a new setup. Use `--out FILE` to choose another output path. Retain the saved JSON with the experiment.

For example, save a Spot setup to a known path:

```bash
uv run python scripts/command_edit.py \
  --task Isaac-HiveBoard-Spot-BallValve-Play-v0 \
  --out configs/spot-ball-valve-review.json --port 9080
```

After clicking **Save setup**, run:

```bash
uv run python scripts/play.py \
  --task Isaac-HiveBoard-Spot-BallValve-Play-v0 \
  --setup configs/spot-ball-valve-review.json \
  physics=newton_mjwarp --visualizer newton
```

Use `--no-setup` with `play.py` to inspect the command sequence defined in the task code.

## Record several environments

The batch recorder runs each selected environment in a separate process and writes MP4 files, logs, and a `summary.json` under `videos/environments/<timestamp>/`.

Preview the default selection:

```bash
uv run python scripts/record_all_envs.py --list
```

The default selection contains `-Play` environments, including the light-bulb tasks for all three robots. Add `--all` to include other variants. To record only the ANYmal light-bulb task:

```bash
uv run python scripts/record_all_envs.py \
  --task Isaac-HiveBoard-Anymal-Lamp-Play-v0 --renderer newton
```

Filter by robot and inspect the commands before recording:

```bash
uv run python scripts/record_all_envs.py --match Franka --dry-run
uv run python scripts/record_all_envs.py --match Franka --renderer newton
```

The batch recorder defaults to RTX rendering. Select `--renderer newton` for rasterized output. Both `ffmpeg` and `ffprobe` must be on `PATH`. Frame rates are derived separately for each task to preserve simulated timing.

Inspect the recordings and task outcomes before treating them as successful demonstrations. For light bulb, check the [configured screw travel and success condition](/simulation/isaac-lab#light-bulb-success-condition).

## Record episodes for learning

### Player recordings

When a task has a recorder configured, `play.py` writes HDF5 episodes and prints the output path. The standard recorder defaults to `logs/recorded_datasets/`. The player exports successful and unsuccessful episodes. Use `--no-dataset` when only visualization or video is needed.

Inspect outcome labels before selecting episodes for learning. Check the HDF5 schema against the intended training code.

## Policy training

Reinforcement and imitation learning now live in [`hiveboard-bench/hiveboard-rl`](https://github.com/hiveboard-bench/hiveboard-rl), checked at commit [`34a11c8`](https://github.com/hiveboard-bench/hiveboard-rl/commit/34a11c865923aedc3727eb019a8912401c241625). The core `isaaclab-hiveboard` repository provides environments, scripted controllers, command editing, and recording. Its former `scripts/rl/`, `scripts/imitation/`, and `imitation` dependency extra have been removed.

The learning repository installs its own pinned `isaaclab-hiveboard` submodule. With `just` and `uv` installed, start in a separate checkout:

```bash
git clone https://github.com/hiveboard-bench/hiveboard-rl.git
cd hiveboard-rl
just setup
```

Generate USD assets inside `dependencies/isaaclab-hiveboard` using that checkout's generation recipes, or use `just sync-assets /path/to/isaaclab-hiveboard` to copy generated assets from a checkout matching the pinned core version. Then run `just list-envs` to inspect the combined core and learning registry. Keep the learning repository commit and its core submodule commit with experiment records.

### Reinforcement learning

The learning package registers ANYmal `-RL-v0` and `-RL-Play-v0` tasks for `BallValve`, `SmallValve`, `M30Thread`, and `CircuitBreaker`.

The maintainers identify **cuRobo trajectory bank → PPO student → evaluation** as the current working workflow. The bank supplies reset states, tracking rewards, and deviation terminations. The actor uses deployable observations; the critic also receives privileged simulator state.

Follow the [learning README](https://github.com/hiveboard-bench/hiveboard-rl/blob/34a11c865923aedc3727eb019a8912401c241625/README.md#usage) and [justfile](https://github.com/hiveboard-bench/hiveboard-rl/blob/34a11c865923aedc3727eb019a8912401c241625/justfile) for `rl-bank`, `rl-student-ppo`, `rl-eval`, and `rl-play`. Select the same `RL_TOOL` for bank generation, training, and evaluation. Set parallel environment counts to fit the available GPU memory.

Inspect each task's success condition and reset distribution before training. Report the configured goal and validate the complete [benchmark motion](/benchmark/tasks) before submitting an evaluation.

### Imitation learning

Behavior cloning, DAgger, teacher training, and student distillation remain alternative workflows in the learning repository. Its `il-collect`, `il-train`, `il-dagger`, and `il-eval` recipes use the imitation-learning scripts and their dataset layout. Follow the [learning repository instructions](https://github.com/hiveboard-bench/hiveboard-rl/blob/34a11c865923aedc3727eb019a8912401c241625/README.md#usage) for these workflows; a core player recording is not automatically a compatible training dataset.

## Simulation datasets and DataHive

Use [DataHive](/guides/datahive) for its recording integrations, episode annotations, validation, and dataset submission workflow. The simulation player exports its own HDF5 datasets. Using the same benchmark does not establish file-format compatibility. Check observation names, action units, coordinate frames, timestamps, and metadata before converting data between pipelines.

A [learning-dataset contribution](/contribute/evaluations) has no fixed episode count. Include the simulator commit, task configuration, controller or policy, reset distribution, and outcome labels with simulated data. Keep this separate from a scored benchmark submission, which requires **13 conditions with five trials each**.

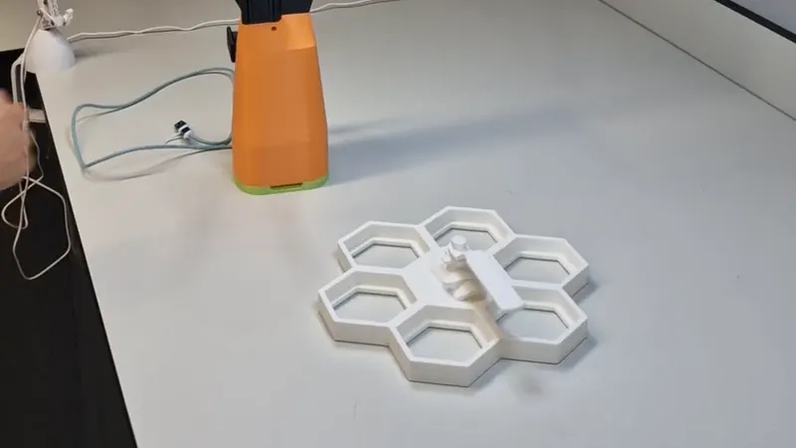
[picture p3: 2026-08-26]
public/assets/posters/macao_torque_valve.webp

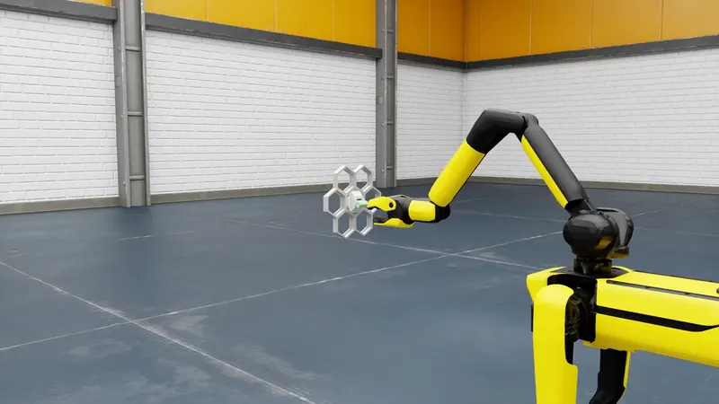
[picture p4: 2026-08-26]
public/assets/posters/sim_spot_circuit_breaker.webp

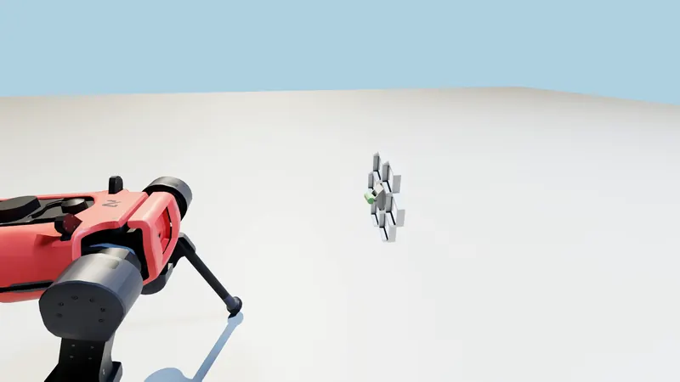
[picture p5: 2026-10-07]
public/assets/posters/anymal_d_isaac_circuit.webp

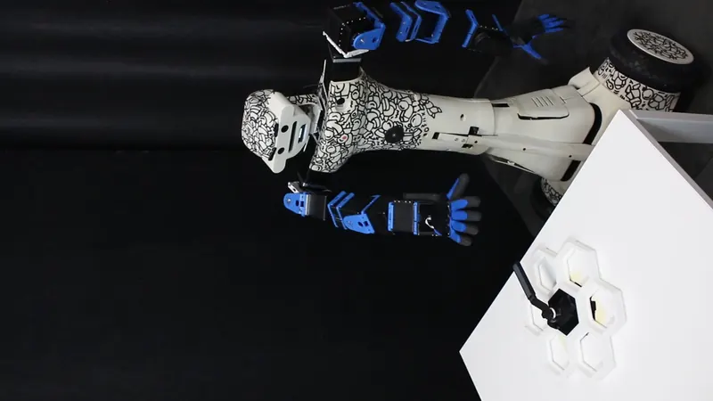
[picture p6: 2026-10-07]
public/assets/posters/ALTER_EGO_ring_ball_valve.webp

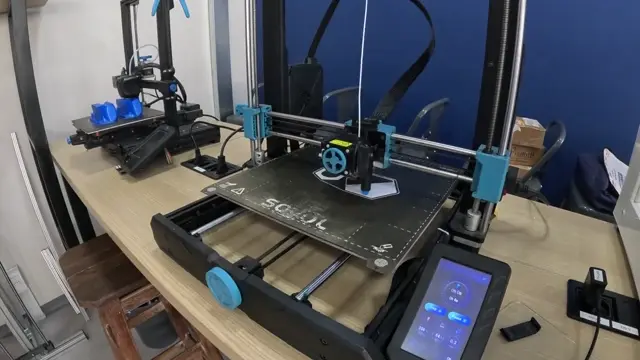
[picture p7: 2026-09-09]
public/assets/posters/video_2.webp

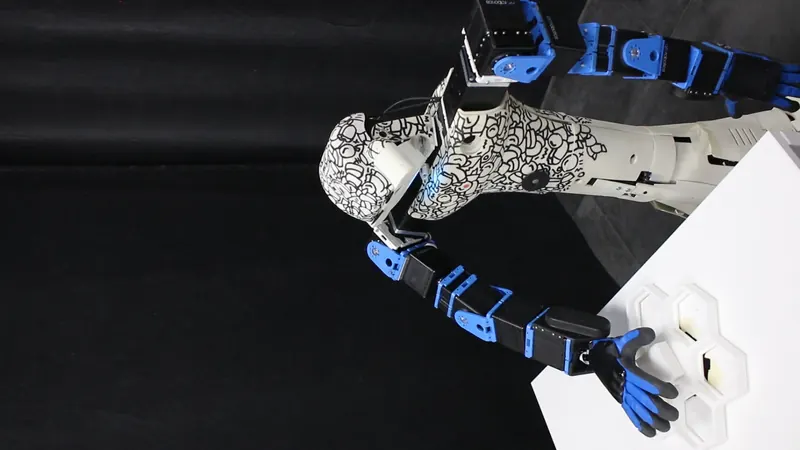
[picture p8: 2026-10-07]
public/assets/posters/ALTER_EGO_button.webp

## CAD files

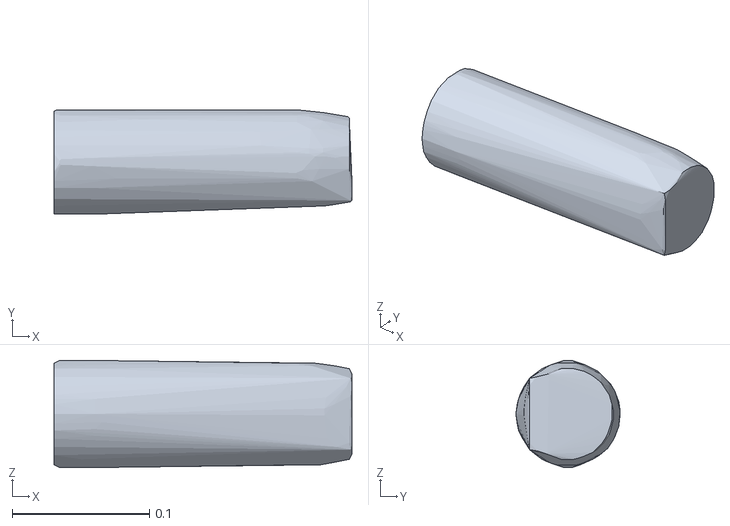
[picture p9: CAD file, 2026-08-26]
public/sim/models/assets/spot/arm_link_el1_main.obj
0.217 x 0.076 x 0.078

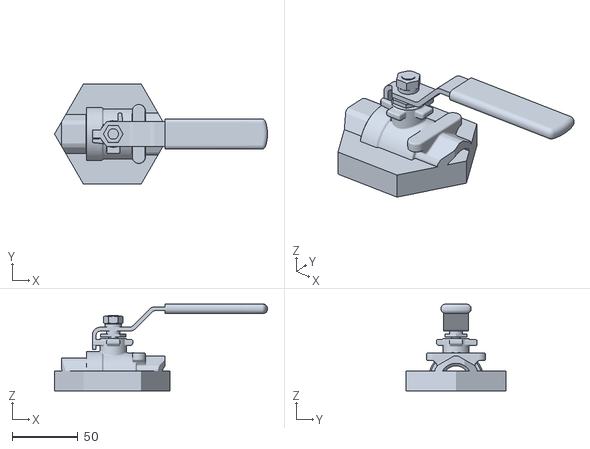
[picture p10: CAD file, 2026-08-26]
public/models/composed_assembly/Ball_Valve_Assembly.stl
162.3 x 76.3 x 66.1

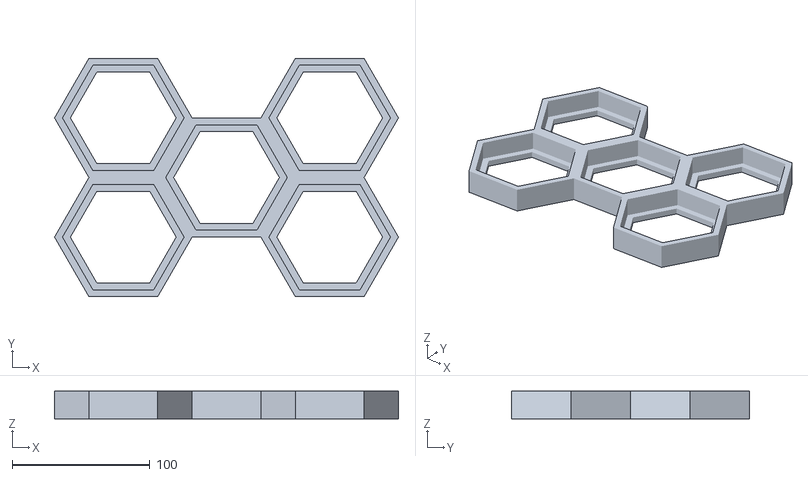
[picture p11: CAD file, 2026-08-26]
public/models/boards/Honeycomb_Panel_M.stl
250.0 x 173.2 x 20.0

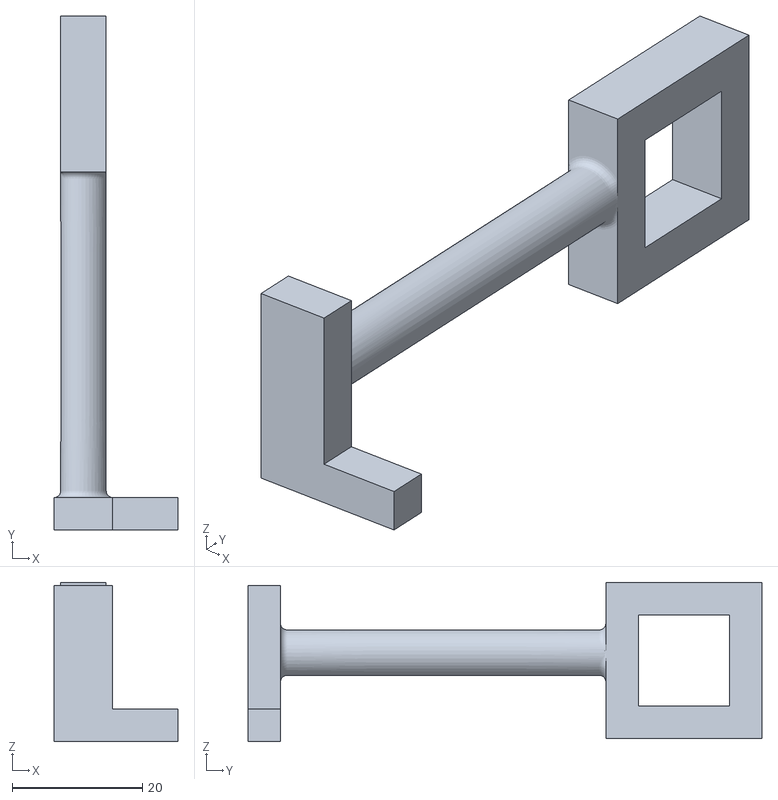
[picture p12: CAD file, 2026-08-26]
public/models/composed_assembly/Key.stl
19.0 x 79.0 x 24.5

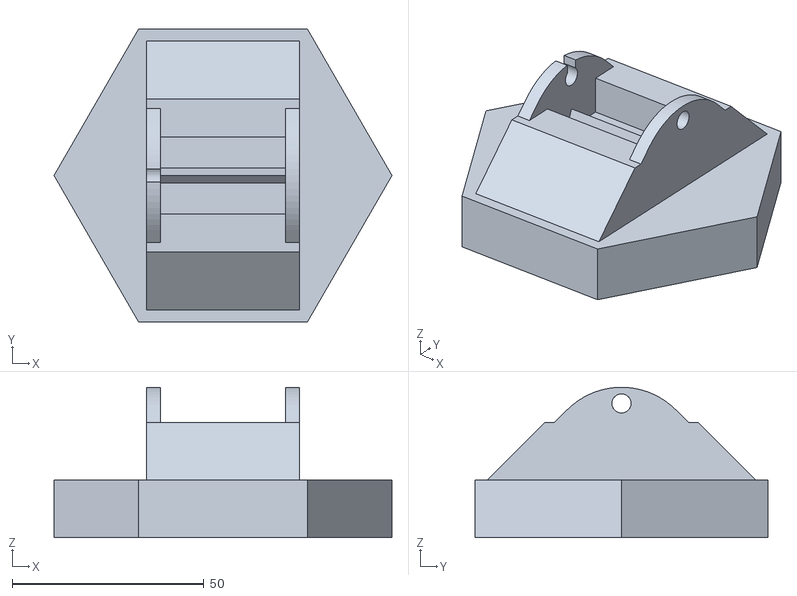
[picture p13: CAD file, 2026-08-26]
public/models/precision_based/Circuit_Breaker_Base.stl
88.1 x 76.3 x 39.2

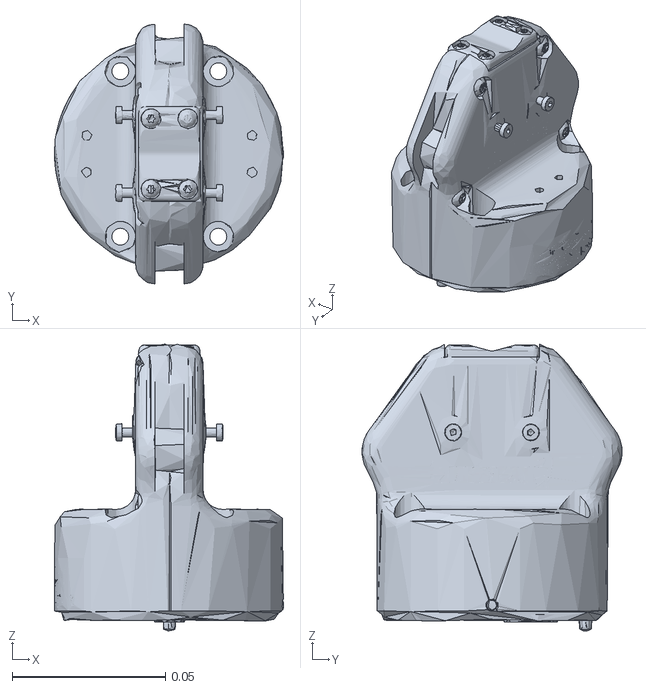
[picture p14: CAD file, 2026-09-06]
public/sim/models/assets/anymal/anymal_055_robotiq_base_link.obj
0.0748 x 0.0849 x 0.0937

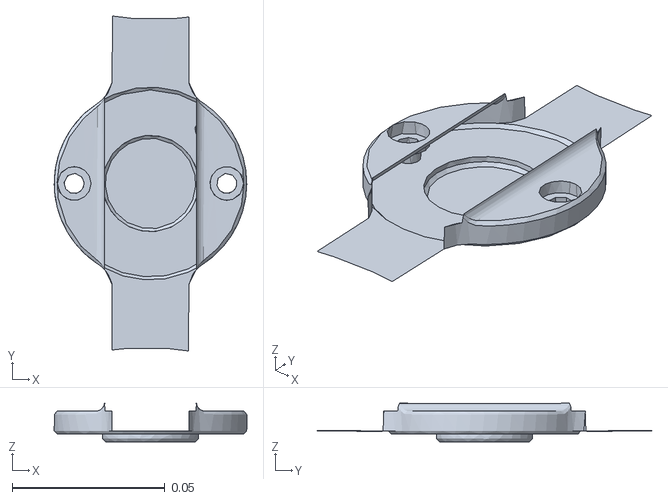
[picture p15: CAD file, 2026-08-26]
public/sim/models/assets/fr3/hand_4.obj
0.063 x 0.11 x 0.0126

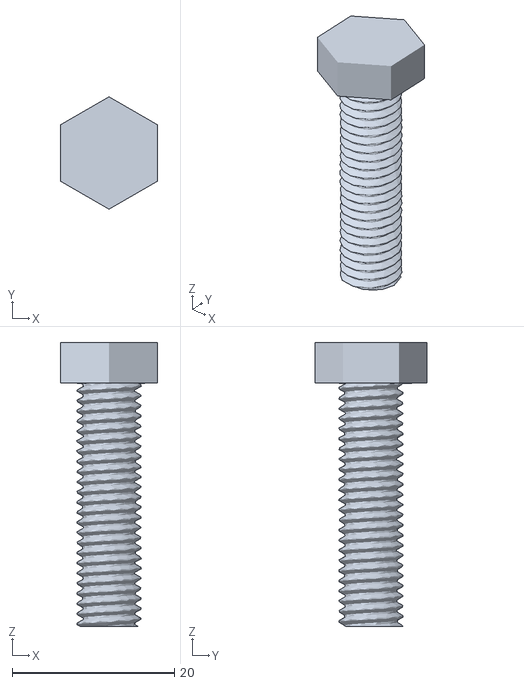
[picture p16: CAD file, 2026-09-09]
public/sim/models/assets/hb/shock-absorber_MeshInstance_1_Corpo1.obj
12.0 x 13.9 x 35.0

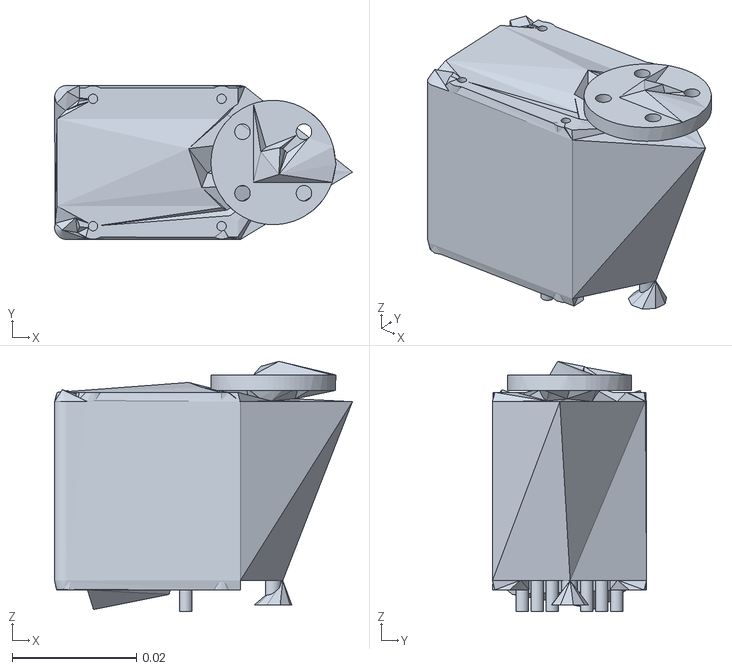
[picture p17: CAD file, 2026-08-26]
public/sim/models/assets/so101/sts3215_03a_no_horn_v1.obj
0.048 x 0.0248 x 0.0403

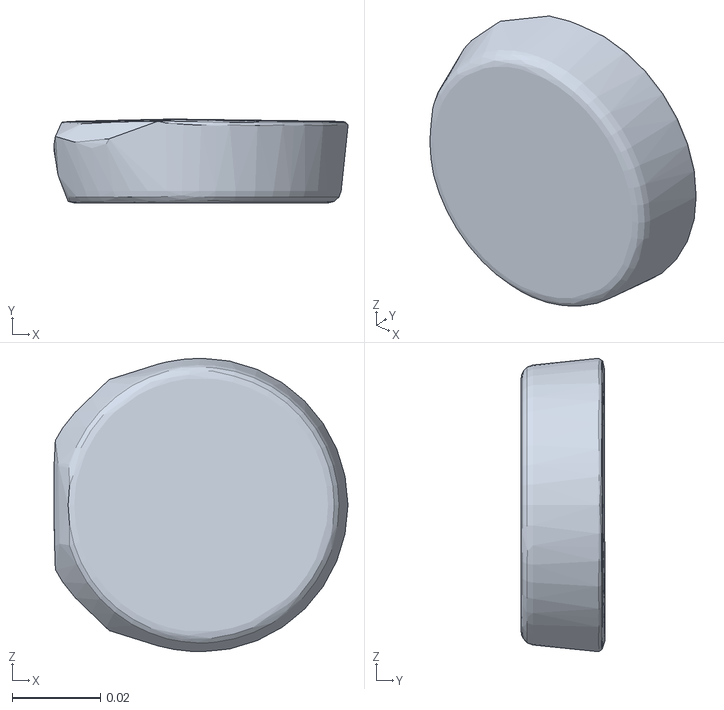
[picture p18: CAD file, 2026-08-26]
public/sim/models/assets/spot/arm_link_el1_lip.obj
0.0666 x 0.019 x 0.0665

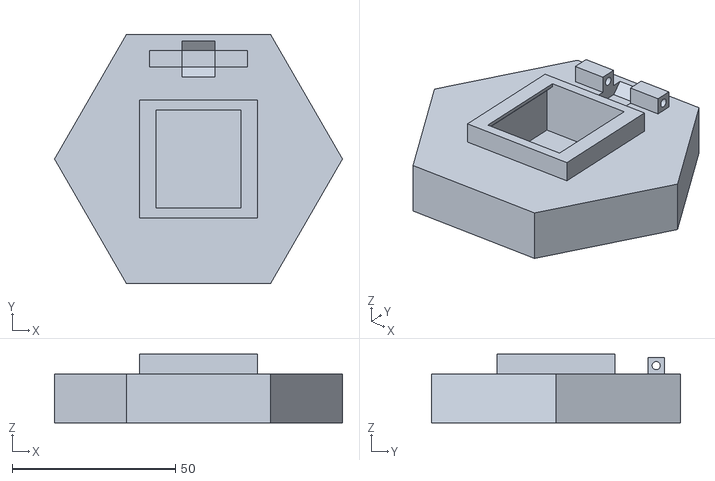
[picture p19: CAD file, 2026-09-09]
public/sim/parts/precision_based/Button_Base.stl
88.1 x 76.3 x 21.0

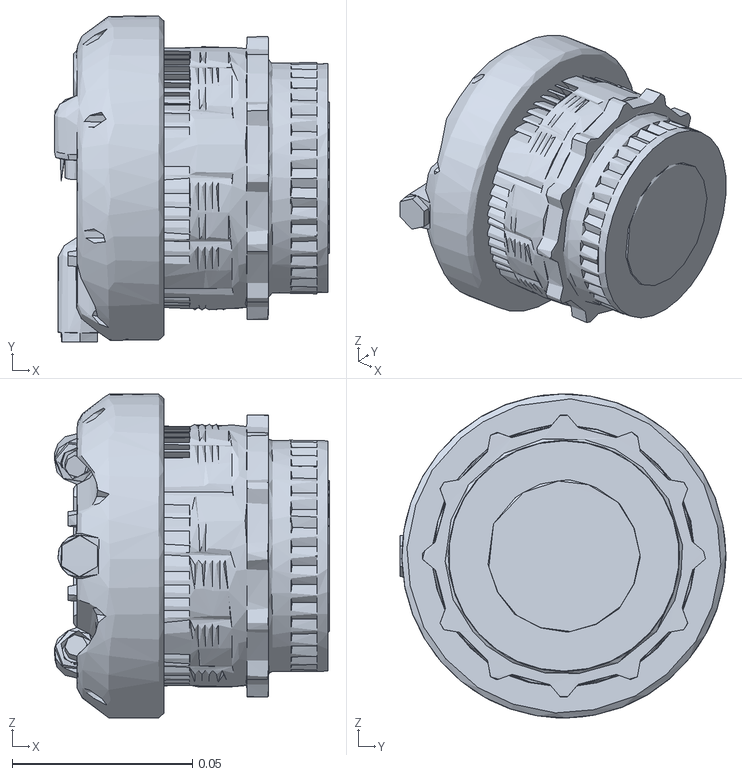
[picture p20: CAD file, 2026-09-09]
tools/assets/anymal/dynaarm_elbow_dark.obj
0.0765 x 0.0905 x 0.09

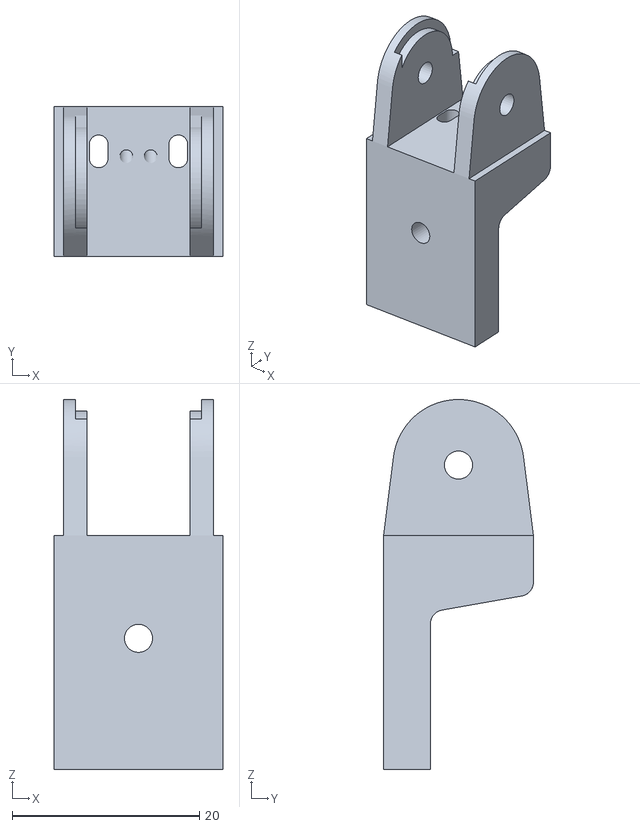
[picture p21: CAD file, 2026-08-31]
tools/assets/macao/Finger Base.stl
18.0 x 16.0 x 39.5

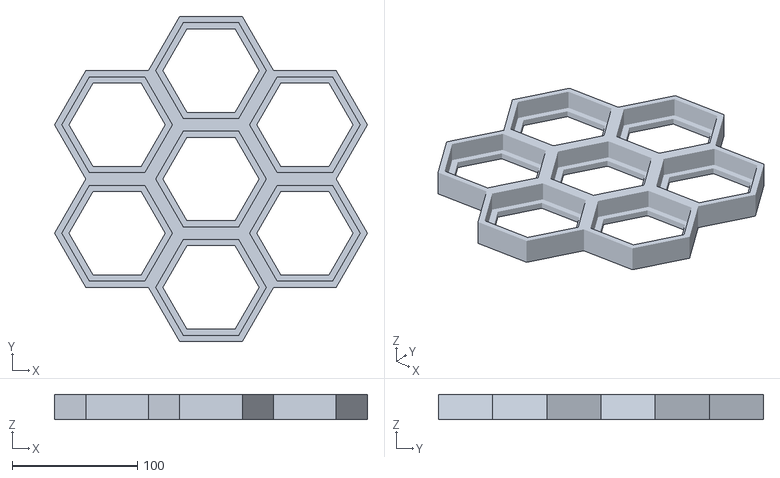
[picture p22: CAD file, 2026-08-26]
public/models/boards/Honeycomb_Panel.stl
250.0 x 259.8 x 20.0

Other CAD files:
public/models/composed_assembly/Half_Lamp.stl
public/models/precision_based/Button_Base.stl
public/sim/models/assets/anymal/anymal_052_right_inner_finger.obj
public/sim/models/assets/fr3/link1.obj
public/models/boards/Honeycomb_Panel_S.stl
public/models/composed_assembly/Ball_Valve_Base.stl
public/models/composed_assembly/Ball_Valve_Friction_Ring_Set.stl
public/models/composed_assembly/Ball_Valve_Lever.stl
public/models/composed_assembly/Button_Cover.stl
public/models/composed_assembly/Button_Spring.stl
public/models/composed_assembly/Drawer.stl
public/models/composed_assembly/Drawer_Base.stl
public/models/composed_assembly/Key_Base.stl
public/models/composed_assembly/Lamp_Base.stl
public/models/composed_assembly/Lamp_Screw.stl
public/models/composed_assembly/Shock_Absorber.stl
public/models/composed_assembly/Shock_Absorber_Base.stl
public/models/composed_assembly/Shock_Absorber_Pin.stl
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

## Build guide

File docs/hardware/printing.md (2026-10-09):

# Print the parts

The printable files are stored in the [`STL/` directory](https://github.com/hiveboard-bench/HiveBoard/tree/main/STL). Source geometry and mesh exports are available separately in [`CAD/`](https://github.com/hiveboard-bench/HiveBoard/tree/main/CAD).

The optional [ArUco cell](/hardware/aruco-cell) uses two OBJ parts, printed separately in white and black PLA. Follow its import-scale and assembly instructions.

::: tip Check the fit first
Before printing the full set, print one honeycomb cell and one attachment base. Verify that the attachment seats fully, remains stable during manipulation, and can be removed without damaging either part.
:::

## Printer requirements

| Item | Recommendation |
|---|---|
| Process | Consumer-grade FDM |
| Material | PLA, 1.75 mm |
| Minimum build area | 300 × 300 mm for the complete base |
| Nozzle | 0.4 mm |
| Layer height | 0.20 mm |
| Wall count | 4 |
| Top / bottom layers | 5 / 5 |
| Print speed | 50 mm/s |
| Nozzle temperature | 200–220 °C |
| Bed temperature | 50–60 °C |
| Cooling | 100% |
| Adhesion | Skirt or brim |
| Supports | Only where required |

Smaller variants of the honeycomb panel are included in the repository, but the full benchmark geometry is designed around a 300 × 300 mm build area.

## Infill by part type

| Part type | Infill |
|---|---:|
| Base structure | 20% |
| Mechanical parts | 25% |
| Torque components | 30% |
| Threads | 25% |
| Decorative covers | 15% |

## Orientation

| Component | Orientation |
|---|---|
| Threads and screws | Vertical |
| Nuts | Flat |
| Valves | Handle up |
| Drawer | Largest face on the bed |
| Pegs | Vertical |
| Shock absorber parts | Sideways |

## Print order

For a new printer or filament batch, use this order:

1. Print one honeycomb cell and one simple attachment base.
2. Check the press fit and dimensional consistency.
3. Print the M8 and M30 test pieces before the complete threaded attachments.
4. Print the base panels.
5. Print the remaining functional mechanisms.

This order catches tolerance and thread problems before the longest prints.

## Post-processing

- Remove stringing and support material without rounding functional edges.
- Check that mating faces seat fully.
- Test threads by hand before mounting the attachment.
- Apply light sanding only when printer calibration produces tight surfaces.
- Record any sanding or dimensional adjustment in the trial notes.

Do not lubricate or modify friction surfaces without reporting the change. These changes can alter the task difficulty.

## Files to download

| Group | Repository folder |
|---|---|
| Honeycomb base | [`STL/Honeycomb`](https://github.com/hiveboard-bench/HiveBoard/tree/main/STL/Honeycomb) |
| Valves | [`STL/Valves`](https://github.com/hiveboard-bench/HiveBoard/tree/main/STL/Valves) |
| Threads | [`STL/Threads`](https://github.com/hiveboard-bench/HiveBoard/tree/main/STL/Threads) |
| ArUco cell (OBJ/MTL) | [`CAD/ArUco Cell`](https://github.com/hiveboard-bench/HiveBoard/tree/main/CAD/ArUco%20Cell) |
| Other mechanisms | [`STL/`](https://github.com/hiveboard-bench/HiveBoard/tree/main/STL) |

The repository README also links to the current attachment-specific printing guide.

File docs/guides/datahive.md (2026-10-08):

---
description: Collect, annotate, validate, and share HiveBoard learning episodes with DataHive, including data collected during benchmark evaluations.
---

# Data collection with DataHive

[DataHive](https://github.com/hiveboard-bench/DataHive) is a toolkit for collecting HiveBoard manipulation episodes with robot states, control commands, camera recordings, and task annotations. It provides a local browser interface, a Python recording API, validation tools, and upload to a configured Hugging Face dataset repository.

**We encourage labs to collect learning data while running a benchmark evaluation.** Recording the same trials can provide both performance measurements and trajectories for subsequent research. Dataset collection is optional: a benchmark submission still requires all 13 conditions with five trials each, while the [learning-dataset call](/contribute/evaluations) has no fixed episode count or requirement to cover every condition.

## Choose the workflow

| Tool | Purpose | Output |
|---|---|---|
| [Website Evaluation Runner](/benchmark/evaluation-runner) | Time trials, enter outcomes, and prepare a benchmark submission in the browser | Benchmark trial CSV, platform description, and submission package |
| DataHive local Runner and Annotate pages | Organize collection sessions, connect recorded states, commands, and videos to trials, and annotate and validate episodes | HDF5 episodes, camera MP4 files, and an extended annotation CSV |

The website Evaluation Runner does not acquire robot or camera streams. DataHive requires a recording integration with your experimental system; installing the toolkit alone does not connect it to a robot.

## Lab registration and credentials

All manipulation data contributed across laboratories is centralized directly in the official **HiveBoard** repository on Hugging Face (`HiveBoard/<lab_id>`). Labs do not need to create or host separate repositories; all contributions always go directly to our official benchmark Hub storage.

To receive authorization and write access to your designated repository:

1. **Submit the registration form**: Fill out the [DataHive Lab Registration Form](https://docs.google.com/forms/d/e/1FAIpQLScfDJvfcweYjv8bLDEALWOJk1q4mW3xOeB52aUey1VWWp_pxQ/viewform?usp=dialog) with your lab name, institution, robotic platform, and contact email.
2. **Receive credentials**: The HiveBoard team will register your laboratory and provide:
   - Your unique **Lab ID** (`lab_id`, e.g. `labrom`, `cmu_bimanual`);
   - An authentication **Hugging Face write token** allowing DataHive to upload directly to `HiveBoard/<lab_id>`.
3. **Direct upload destination**: All episodes uploaded through DataHive go straight to `HiveBoard/<lab_id>`. This ensures standardized tracking, dataset indexing, and automated aggregation for future benchmark releases.

## Install and configure

Use Python 3.10 or later in a dedicated environment. Install `datahive-tools`:

```bash
pip install datahive-tools
pip install "datahive-tools[video]"   # includes OpenCV for video integrity checks
```

Initialize your lab configuration:

```bash
datahive init
```

The CLI prompts for:
- `Lab ID`: your assigned lab identifier from the registration form;
- `Hugging Face token`: your write token issued by the HiveBoard team.

`init` verifies your token against the Hugging Face Hub (via `whoami()`), writes your configuration to `~/.datahive/config.yaml` with secure `0600` file permissions, and automatically sets the remote repository destination to our official repository `HiveBoard/<lab_id>`.

Next, create the robot profile skeleton:

```bash
datahive new-profile
```

Fill in `samples/robot_profile.yaml` before recording. Describe the robot, end-effector, control mode, state and command conventions, joint order, recording rate, and cameras. See the upstream [robot-profile reference](https://github.com/hiveboard-bench/DataHive/blob/main/src/datahive/skills/datahive-data-prep/reference/robot-profile.md) for field definitions.

From the same working directory, start the interface:

```bash
datahive interface --port 8000
```

Open `http://127.0.0.1:8000` on that computer. Use **Runner** to plan a session or **Annotate** to inspect existing episodes.

## Record a session

Select the task conditions and collection mode. The Runner defaults to five trials per selected condition. Dataset collections can use a subset of conditions and additional sessions; the benchmark's 65-trial requirement is not a dataset-size limit.

| Mode | Recording procedure |
|---|---|
| Manual | Use the countdown and stopwatch, enter the outcome, and attach the HDF5 episode and one MP4 per camera listed in the robot profile. Your experimental system records these files. |
| Automatic | Connect your recording/control script through `CollectClient`. The script receives the queued task, writes states and commands through `EpisodeWriter`, attaches camera recordings, and returns the episode for annotation. The evaluator still determines the outcome. |

Follow the upstream [data format](https://github.com/hiveboard-bench/DataHive/blob/main/src/datahive/skills/datahive-data-prep/reference/layout-and-format.md) when preparing files. For automatic collection, use the [robot integration guide](https://github.com/hiveboard-bench/DataHive/blob/main/src/datahive/skills/datahive-auto-collect/reference/adapting.md). Robot drivers, command generation, and camera acquisition remain part of the lab's integration.

::: tip Reference integration: Franka Research 3
For a complete example to use as a base, see [`fr3_datahive`](https://github.com/hiveboard-bench/fr3_datahive) for a Dockerized setup with ROS 1 Noetic, teleoperation, and DataHive recording on a Franka Research 3 (FR3).
:::

**Record physical trials with an external camera**, with the board, end-effector, and task state visible throughout. Include that camera in the profile when storing its recording with the DataHive episode. For simulation, record rendered camera observations and identify the simulator and configuration.

For Isaac Lab simulation, see [Simulation workflows](/simulation/workflows) for command editing and episode recording, plus links to the separate learning repository. The simulation player exports its own HDF5 layout. Check the data schema and metadata before converting its output into DataHive episodes.

### Check the recording setup first

DataHive currently expects aligned state and command arrays in HDF5, a proprioception rate of at least 100 Hz, and one MP4 per configured camera. Its video checks require matching camera resolution, frame rate, and frame count; each image dimension must be 180–1280 pixels, and video duration must match the episode within 0.5 seconds. Check the upstream format reference when choosing acquisition settings.

Record and validate a short pilot episode before starting the collection. Preserve the original streams and timestamps and document any conversion. If your system cannot meet these constraints, discuss an alternative format with the organizers before collection. The dataset call also welcomes depth, force/torque, tactile, and other signals; agree on supplemental files for modalities outside DataHive's current episode format.

### Optional board localization

The [ArUco cell](/hardware/aruco-cell) can provide a visual reference for board pose during collection. Retain the camera calibration, measured marker size, marker-to-board transform, and timestamped images used for detection. Store any estimated poses with their frame conventions and timestamps. Marker detection and pose estimation are part of the lab's recording integration. Keep calibration records with the session metadata and agree on supplemental files with the organizers where needed.

## Annotate and validate

The local interface supports review and validation. The equivalent command sequence for an existing episode is:

```bash
datahive check EPISODE_ID
datahive annotate EPISODE_ID
datahive validate EPISODE_ID
```

Replace `EPISODE_ID` with the recorded episode identifier. `check` inspects recording integrity before annotation. `annotate` records task outcome and related fields; `validate` checks the episode and annotation together. Inspect both errors and warnings.

Use the [task definitions](/benchmark/tasks) and [counting conventions](/benchmark/logging) for outcomes, stages, attempts, and regrasps. Preserve unsuccessful episodes and label interventions, resets, and aborted recordings. A benchmark trial may contain several attempts or regrasps; these do not become separate scored trials.

## Collect during a benchmark evaluation

1. Test recording and synchronization before the scored trials. Keep familiarization and training episodes identifiable and separate from the evaluation set.
2. Follow the [evaluation protocol](/benchmark/protocol), including all 13 conditions, five trials per condition, fixed control settings, neutral starting poses, resets, and task timeouts. Use the required separate blocks for the two ball-valve configurations.
3. Record the same trial's states, commands, and camera streams. Maintain an index linking its DataHive session and episode IDs to the benchmark `trial_id` and `attachment_id`; session trial numbers may follow a different order from the benchmark template.
4. Time the benchmark trial from the first commanded task motion until success, a safety stop, or timeout. Save a completion time only for successful trials. A recording may include time before or after the task, so its total duration is not automatically the benchmark completion time.
5. Prepare the benchmark log and [submission package](/benchmark/results) separately from the learning dataset. Report every scored trial, including failures, and retain the external-camera recording for each one.

DataHive's `trials.csv` contains extra annotation fields and is **not a drop-in replacement for the benchmark CSV**. For the benchmark submission, use the website Evaluation Runner or transfer the scored results into the [benchmark template](/benchmark/logging), preserving its condition-to-trial mapping and filling all required counts and stages. Keep a correspondence to the original episode IDs. Do not copy DataHive's operator and annotator names into the public benchmark files.

To generate the benchmark submission ZIP, enter the scored results and platform details in the website Evaluation Runner. It does not currently import DataHive CSV files. The template can be used to prepare the records before entry.

Passing DataHive validation checks an episode's format and annotations; it does not establish that all 65 benchmark trials or the full evaluation protocol have been completed. Data collected during evaluation can be contributed for future training, but must remain excluded from training or tuning the policy whose performance those trials report.

## Upload to Hugging Face Hub

DataHive synchronizes local manipulation sessions directly with our official Hugging Face dataset repository (`HiveBoard/<lab_id>`). Labs do not create external repositories; all data contributes directly to the central HiveBoard repository.

### Upload a single episode

After reviewing and validating an episode, upload it using the CLI:

```bash
datahive upload EPISODE_ID
```

Before uploading, DataHive runs a preflight check to confirm that the episode status is `validated` and directory structure constraints are satisfied. When confirmed, DataHive:
- uploads the trajectory array to `{session_id}/episodes/{episode_id}.h5`;
- uploads each camera recording to `{session_id}/episodes/{camera_name}.mp4`;
- uploads `{session_id}/setup.jpg` if present;
- automatically downloads and merges `{session_id}/trials.csv` directly in the HiveBoard repository, keeping remote records synchronized with local additions;
- marks the episode status as `uploaded` in the local index (`samples/.datahive/index.sqlite`).

Use `--yes` (`-y`) to skip the confirmation prompt, or `--force` to re-upload an already uploaded episode.

### Synchronize all sessions (`datahive sync`)

To reconcile your entire local `samples/` directory with our Hugging Face repository in one command:

```bash
datahive sync
```

`sync` scans all sessions under `samples/`, detects any validated episodes that have not yet been uploaded, pushes them directly to `HiveBoard/<lab_id>`, and merges all corresponding `trials.csv` files on the Hub.

Use `--dry-run` to preview what would be uploaded without transferring files:

```bash
datahive sync --dry-run
```

### Uploading from the web interface

Both operations are also accessible in the local web interface (`datahive interface`):
- In the **Annotate** view, click the **Upload** button on any validated episode card to upload it immediately to `HiveBoard/<lab_id>`.
- In the header, click **Sync** to reconcile all sessions with the Hub.

### Remote repository layout

All contributed episodes are organized inside our official dataset repository:

```text
HiveBoard/<lab_id>/                  # Official HiveBoard dataset repository
├── 2026-09-20_session_01/
│   ├── episodes/
│   │   ├── episode_0001.h5          # States, commands, and joint telemetry
│   │   ├── camera_wrist.mp4         # Synchronized camera video
│   │   ├── camera_external.mp4      # External view video
│   │   └── ...
│   ├── trials.csv                   # Session trials and outcome annotations
│   └── setup.jpg                    # Platform setup photo
└── ...
```

### Submitting for organizer review

Because all uploads go directly to our official HiveBoard repository:
- You do not need to configure external storage, manage third-party repositories, or transfer archives manually.
- When you finish collecting a session or dataset, simply email **ricardo.godoy@usp.br** with your `lab_id`, platform description, and covered tasks, as detailed in the [dataset submission instructions](/contribute/evaluations#send-the-data-for-review). The HiveBoard team will review the uploaded episodes directly in `HiveBoard/<lab_id>`.

Record the DataHive package version or commit with the dataset. DataHive builds on the architecture and workflows of [Oopsie Data](https://github.com/oopsie-data); see its [README](https://github.com/hiveboard-bench/DataHive#readme) for project credits and current usage.

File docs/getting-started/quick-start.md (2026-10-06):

# Getting started

Build and evaluate the printed board, or load the articulated models in a simulator.

## Build the physical benchmark

1. Review the [printing requirements](/hardware/printing).
2. Print one base cell and one attachment to check the press fit.
3. Print and [assemble the full benchmark](/hardware/assembly).
4. Read [How to perform each task](/benchmark/tasks) for all 13 conditions, including both ball-valve configurations.
5. Follow the [evaluation protocol](/benchmark/protocol).
6. Record five trials per condition with the [Evaluation Runner](/benchmark/evaluation-runner) or [CSV or XLSX template](/benchmark/logging).

## Evaluate an existing board

1. Check every attachment for damage, free motion, and secure seating.
2. Fix the base to a rigid surface and document its orientation.
3. Open [How to perform each task](/benchmark/tasks) and check the initial state, required actions, success criterion, timeout, and reset for each mechanism.
4. Complete familiarization before recording.
5. Run five recorded trials for all 13 conditions. Record every trial with an external camera.
6. Check the trial entries and include the setup photograph, platform description, and recordings with the results.

Go directly to the [evaluation protocol](/benchmark/protocol).

## Collect learning data

Use [DataHive](/guides/datahive) to collect robot states, commands, camera recordings, and task annotations. Configure and validate the recording setup before collection. We encourage labs to record these data during benchmark evaluations; follow the [combined workflow](/guides/datahive#collect-during-a-benchmark-evaluation) to link episodes to the scored trials.

For a dataset contribution, there is no fixed episode count or requirement to cover all conditions. Read the [learning-dataset call](/contribute/evaluations) and contact the organizers before collection.

## Work in simulation

- **Articulated assets:** use the URDF or USD files from the main repository in your own simulator or robotics stack.
- **Isaac Lab environments:** follow the [installation and task reference](/simulation/isaac-lab) to run Spot, Franka FR3, and ANYmal tasks with Newton. The current setup uses Python 3.12 and generated USD assets.
- **Simulation data and policies:** use [Simulation workflows](/simulation/workflows) to edit command sequences, record episodes, and train or evaluate policies.

Read [Simulation assets](/simulation/assets) before selecting the implementation. The physical and simulation parameters should be reported separately because friction, contact, and press-fit behavior vary between printed instances.

## Minimum reporting package

A physical benchmark result should identify:

- the HiveBoard release or commit;
- printer, material, and any post-processing;
- board mounting orientation;
- robot and end-effector;
- control interface or policy;
- the completed trial log; and
- any broken, replaced, or reseated parts.

Include `setup.jpg` and all 65 trial recordings. The runner exports the trial log and platform description, and lists the required video filenames. Incomplete sessions can be saved and resumed; a submission must contain all 65 trials.

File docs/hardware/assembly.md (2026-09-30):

# Assemble and mount

Check that each mechanism moves through its full range and remains seated during manipulation.

## Before assembly

Inspect all printed parts for:

- warped mounting faces;
- incomplete threads;
- support material inside holes or tracks;
- cracks around thin mechanisms; and
- loose press-fit interfaces.

Replace damaged functional parts rather than forcing them into place.

## Assemble the base

1. Place the honeycomb base on a flat surface.
2. Check that all seven cells are clear and dimensionally consistent.
3. Insert one attachment base and press evenly until it is fully seated.
4. Remove and reinsert the test attachment to confirm repeatable fit.
5. Repeat the seating check across the cells you intend to use.

## Assemble the mechanisms

The repository groups all parts required by each attachment in a dedicated STL folder. Keep the printed components from each folder together during assembly.

### Threaded parts

Engage the part by hand without axial forcing. It should advance smoothly while remaining constrained by the thread. If it binds, remove debris and test the matching calibration piece before sanding the final component.

### Ball valve and friction rings

Assemble the ball valve without a ring first. The ring configuration is evaluated as a separate condition and should only be fitted for the corresponding trial block.

### Button {#covered-button}

Confirm that the cover opens freely and that the button returns after it is pressed. Both stages must remain visually distinguishable.

### Drawer

Check the full pull-and-push travel. The drawer must not disengage unintentionally from its base during normal use.

### Lock and key

Check insertion and rotation manually. The initial key position must be repeatable across trials.

### Shock absorber

Confirm that the loose part of the shock absorber can be grasped, aligned with the pin, and fully inserted onto it. This attachment occupies two adjacent cells; reserve both before arranging the board.

## Optional ArUco cell

The [ArUco cell](/hardware/aruco-cell) provides a camera-visible reference for board localization. Fit the black insert into the white base and optionally glue the mating surfaces. Mount it in an available cell with a clear camera view, leaving the task cells and robot approach unobstructed. Record its position and orientation relative to the board.

## Mount the board

Fix the base to a rigid surface within the platform's working volume. Horizontal tabletop and vertical fixture mounting are both allowed, but the orientation must be reported because it changes the approach direction and the likelihood of an attachment releasing from its cell.

Before recorded trials:

1. fully seat every attachment;
2. confirm that all attachments are reachable without moving the base during a trial;
3. check for collision risks around the fixture;
4. photograph the setup as `setup.jpg`; and
5. describe the mounting orientation in `platform.md`.

::: warning Dynamic loading
High-gain or jittering commands can damage printed mechanisms or loosen press-fit attachments. Inspect the board before every session and after any contact that visibly displaces an attachment.
:::

Continue with the [evaluation protocol](/benchmark/protocol).

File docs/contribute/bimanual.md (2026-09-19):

---
description: Contribute HiveBoard attachments requiring coordinated manipulation with two hands or end-effectors.
---

# Open call: bimanual manipulation

We seek functional attachments that require **coordinated manipulation by two hands or end-effectors**. The task should specify what each hand does and why both are needed.

## Suitable proposals

Possible directions include:

- holding a movable body while turning or releasing another component;
- keeping a spring-loaded mechanism open while inserting a second part;
- aligning two movable components before joining them; and
- applying tension with one hand while the other routes or fastens a flexible element.

These are examples to discuss with the authors, not a list of approved designs. Explain whether the task requires simultaneous action, a supporting grasp, or a transfer between hands. Two independent tasks performed side by side are insufficient to demonstrate coordination.

## Design requirements

- Define the role of each hand, including any allowed role exchange.
- Explain which component remains movable and why mounting the attachment does not replace the supporting hand.
- Specify the mounting arrangement, occupied cells, clearance, and approach directions.
- State whether either hand may release and regrasp during each stage.
- Define measurable intermediate stages, overall success, and the reset procedure.
- Ensure the camera view shows both end-effectors and the relevant mechanism state.
- Provide the articulated model and demonstrate the physical sequence with both hands visible. State whether the demonstration uses human hands or robots.

## Propose an attachment {#propose-an-asset}

Email [ricardo.godoy@usp.br](mailto:ricardo.godoy@usp.br?subject=HiveBoard%20bimanual%20attachment%20proposal) with:

1. Your name, affiliation if applicable, and proposed attachment name.
2. The task and the role of each hand.
3. A sketch showing the mounting arrangement and moving parts.
4. The initial state, coordinated sequence, success condition, and reset procedure.
5. The files and physical or simulation testing you expect to provide.

**Contact the authors before starting detailed design** to check whether the task requires the intended coordination and fits the benchmark. See [requirements and credit](/contribute/requirements) for the complete submission package and authorship eligibility.

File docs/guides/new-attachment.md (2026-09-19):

# Add a new attachment

An attachment is part of the benchmark only when its physical geometry, simulation model, task definition, and evaluation metadata agree.

For the [ADL and bimanual open calls](/contribute/), contact the authors before starting the design. Read the [submission requirements and credit policy](/contribute/requirements) alongside this technical guide.

## 1. Reuse the mounting interface

Start from the existing press-fit geometry in the CAD repository. Do not redraw the interface from measurements when an editable source is available.

The attachment should:

- seat fully in a standard honeycomb cell;
- resist the expected manipulation load;
- remain removable without damaging the base;
- avoid interfering with neighboring cells; and
- preserve a repeatable initial state.

For an attachment wider than one cell, document exactly which adjacent cells must remain free.

## 2. Define the task

Write the task definition before producing the final model:

- initial state;
- required manipulation sequence;
- observable success state;
- timeout;
- number and names of intermediate stages, if any;
- permitted reset procedure; and
- likely failure modes.

A success condition must be measurable across different platforms without requiring access to internal robot state.

## 3. Produce the physical files

Provide:

- editable CAD source;
- STL files with descriptive names;
- a complete bill of printed components;
- print orientation and support requirements;
- assembly instructions; and
- a photograph or render of the assembled mechanism.

If the mechanism requires non-printed hardware, list the exact specification and a generally available alternative.

## 4. Produce the articulated model

The simulation asset should include:

- visual and collision geometry;
- named joints and links;
- joint axes, limits, and initial values;
- mass and inertia values with their derivation;
- contact and friction assumptions; and
- a smoke test that drives the mechanism through its full range.

Keep identified parameters separate from nominal defaults when they depend on a particular printed instance.

## 5. Extend the protocol

Propose a stable lowercase `attachment_id` and supply the task metadata for review. Once the attachment is accepted into a versioned benchmark extension, coordinate the following updates with the maintainers:

- the attachment reference;
- the success and timeout table;
- stage numbering, if applicable;
- `trials.csv` and `trials.xlsx`;
- logging validation; and
- the reproducibility checklist.

The current benchmark still requires all 13 conditions, with five trials each. A proposed attachment does not replace an existing condition or change the current runner's required trial count.

## 6. Submit the contribution

Include physical and simulation evidence in the pull request:

- photograph of the assembled attachment;
- manual actuation through the full range;
- successful fit in the HiveBoard base;
- simulation load test; and
- one completed example trial row.

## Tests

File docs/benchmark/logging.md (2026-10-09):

# Record trials

Use the supplied spreadsheet during experiments and the CSV for scripts or data exchange.

The [Evaluation Runner](/benchmark/evaluation-runner) provides a guided timer and produces the same CSV format directly in the browser. It can also save transferable sessions, validate a complete evaluation, and generate the final submission package.

<ul class="doc-links">
  <li><a href="https://github.com/hiveboard-bench/HiveBoard/raw/main/Documentation/trials.xlsx"><strong>Download the XLSX template</strong></a> — for manual entry, with all trial rows pre-populated.</li>
  <li><a href="https://github.com/hiveboard-bench/HiveBoard/raw/main/Documentation/trials.csv"><strong>Download the CSV template</strong></a> — for scripts, version control, and automated validation.</li>
</ul>

Use the [task-name and identifier table](/reference/terminology#task-names-and-identifiers) to match each record to its task.

Do not change `trial_id` or `attachment_id`. Fill the remaining columns while running the trials.

## Logging with DataHive

[DataHive](/guides/datahive) links learning episodes to trial annotations. Its session `trials.csv` has additional fields and is not the benchmark template described here. When collecting data during evaluation, prepare the benchmark CSV with the columns below and keep an index mapping each scored trial to its DataHive session and episode. Session trial numbers may differ from the template's fixed condition assignments. See the [combined workflow](/guides/datahive#collect-during-a-benchmark-evaluation) before transferring results.

## Column reference

| Column | Required entry |
|---|---|
| `lab_id` | Stable lowercase identifier for the laboratory |
| `platform_id` | End-effector and control-interface combination, using lowercase and underscores |
| `date` | `YYYY-MM-DD` |
| `outcome` | `success`, `fail`, `timeout`, or `safety_stop` |
| `failure_cause` | Required when outcome is not `success`; blank otherwise |
| `completion_time_s` | Decimal seconds for successful trials only |
| `n_attempts` | Discrete task attempts, counted from 1 |
| `n_regrasps` | Release-and-grasp events, counted from 0 |
| `stage_reached` | Last completed stage, only for composed assembly tasks |
| `strategy` | `prehensile` or `non_prehensile` |
| `notes` | Deviations, adjustments, damage, or other concise observations |

## Counting conventions

### Attempts

An attempt ends when the current approach is abandoned and a new approach begins. Corrective motion within one continuous approach does not create another attempt. Every trial has at least one attempt.

### Regrasps

Count each time the end-effector releases a part and closes on it again. A trial with one grasp and no release records `0`. A restarted approach adds an attempt; it adds a regrasp only if the part is released and grasped again.

### Strategy

Use `prehensile` when the end-effector closes around and holds the part. Use `non_prehensile` for pushing, pressing, or engaging a feature without an enclosing grasp.

### Stages

Enter the number of the last completed stage, not the stage where the attempt stopped. Enter `0` if stage 1 was not completed.

## Valid example

```csv
trial_id,lab_id,platform_id,attachment_id,date,outcome,failure_cause,completion_time_s,n_attempts,n_regrasps,stage_reached,strategy,notes
1,usp_crob,franka_2f85,valve_gate_small,2026-04-26,success,,34.2,1,0,,prehensile,
2,usp_crob,franka_2f85,valve_gate_small,2026-04-26,fail,slip,,3,2,,prehensile,handle slipped
56,usp_crob,franka_2f85,lock,2026-04-26,success,,142.3,2,1,3,prehensile,
```

## Common mistakes

| Avoid | Use instead |
|---|---|
| Milliseconds or values with `s` appended | Decimal seconds as a plain number |
| `timeout` written in the time column | Set outcome to `timeout` and leave time blank |
| Regrasps counted from 1 | Count release-and-grasp events from 0 |
| Blank counts on failed trials | Record attempts, regrasps, and strategy on every row |
| Blank stage on a failed composed assembly task | Record the last completed stage, including `0` |
| Replacing a damaged-part trial with a clean rerun | Preserve the trial and explain the event in `notes` |

See the [column-by-column instructions](https://github.com/hiveboard-bench/HiveBoard/blob/main/Documentation/HOW_TO_FILL_TRIALS.md) for the full reference.

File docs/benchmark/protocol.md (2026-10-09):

# Evaluation protocol

This protocol characterizes robot-side performance across HiveBoard attachments. It is suitable for teleoperated arms, wearable interfaces, exoskeletons, and autonomous policies, provided that the control mode is held constant across the recorded trials being compared.

The source protocol is available in [`Documentation/PROTOCOL.md`](https://github.com/hiveboard-bench/HiveBoard/blob/main/Documentation/PROTOCOL.md). Submissions through this documentation require all 13 conditions, with five recorded trials per condition (65 trials).

Before recording, open [How to perform each task](/benchmark/tasks). It lists the starting state, required actions, success criterion, timeout, and reset for every condition, including the [shock absorber](/benchmark/tasks#shock-absorber).

## Required material

- One printed HiveBoard base.
- The complete attachment set, including the four-piece friction-ring accessory for the ball-valve ring condition.
- One manipulation platform: an end-effector plus the system that positions and commands it.
- The [Evaluation Runner](/benchmark/evaluation-runner) or supplied trial logging template.
- An external camera with a view of the board and end-effector.

## Prepare the setup

1. Fix the board to a rigid surface within the platform's working volume.
2. Record whether it is mounted horizontally or vertically.
3. Fully seat every attachment before starting.
4. Position the platform so that the board is not moved during a trial.
5. Save a photograph of the complete setup as `setup.jpg`.
6. Create `platform.md` with the end-effector, control interface or policy, mounting orientation, control mode, and relevant calibration notes.
7. Record the printer, material, print settings, and post-processing. The runner includes these fields in `platform.md`.

## Optional dataset collection

We encourage labs to record robot states, executed commands, and camera streams during evaluation using [DataHive](/guides/datahive). Test the recording setup before the scored trials and link each episode to its benchmark trial record. Dataset collection is optional and does not change the task criteria, timing, or requirement for 65 trials. The [DataHive guide](/guides/datahive#collect-during-a-benchmark-evaluation) explains how to prepare both submissions; the [learning-dataset call](/contribute/evaluations) also accepts larger collections and task subsets outside a formal evaluation.

## Familiarization

Run unrecorded practice trials for each attachment until completion times stabilize. Begin recording after three consecutive practice trials finish within 20% of each other or within the timeout, whichever comes first.

Practice trials are not included in the submitted result.

## Recorded trials

For each platform and evaluation condition:

1. Run **five recorded trials**.
2. Start the end-effector from the same neutral pose.
3. Start the external camera before the countdown. When using the runner, command the first task motion when the countdown reaches zero; this is when timing starts. For manual logging, start timing with the first commanded task motion.
4. Stop timing when the success criterion is met, a safety event occurs, or the timeout expires.
5. Reset the mechanism and neutral pose before the next trial.

Run the ball valve as two separate blocks: five trials without a friction ring and five with the ring fitted.

Do not tune parameters or change the control mode between recorded trials in the same condition. A restarted approach within a trial counts as another attempt. Count a regrasp only when the end-effector releases the part and grasps it again. The initial grasp is not a regrasp. Attempts and regrasps are separate counts; neither starts a new trial.

## Outcomes

Use exactly one of these values:

| Outcome | Meaning |
|---|---|
| `success` | The full success criterion was completed within the timeout |
| `fail` | The trial ended unsuccessfully before the timeout |
| `timeout` | The success criterion was not completed before the limit |
| `safety_stop` | The trial ended because of a safety event |

Only successful trials receive a `completion_time_s` value.

## Failure causes

Every unsuccessful trial must contain one dominant failure cause.

| Cause | Use when |
|---|---|
| `grasp_geometry` | The end-effector cannot engage the part in a stable grasp |
| `kinematic_limit` | The platform cannot produce the motion required by the task |
| `perception` | Alignment or state could not be judged reliably |
| `slip` | A grasp was acquired and then lost |
| `force_limit` | Available grasp or actuation force was insufficient |
| `control_precision` | Control resolution was too coarse for the task |
| `other` | None of the listed causes fits; explain in `notes` |

Choose one dominant cause even when several factors contributed.

## Broken or displaced parts

If a part breaks or leaves its cell:

1. stop the trial if continuation is unsafe;
2. record the trial as it occurred;
3. describe the event in `notes`;
4. reseat or replace the part; and
5. continue with the next scheduled trial.

Do not silently replace the affected row with a rerun.

## Reproducibility checklist

- [ ] The HiveBoard release or commit is recorded.
- [ ] Printing parameters and post-processing are recorded.
- [ ] All attachments are fully seated.
- [ ] Familiarization is complete for every attachment.
- [ ] Five recorded trials exist for all 13 conditions (65 trials total).
- [ ] Timeouts and task criteria match the attachment reference.
- [ ] Every unsuccessful trial has one failure cause.
- [ ] Attempts, regrasps, and strategy are present on every row.
- [ ] Composed assembly tasks include `stage_reached`.
- [ ] Broken or reseated parts are described.
- [ ] `setup.jpg` and `platform.md` accompany the log.
- [ ] One external-camera recording accompanies each trial, using the filenames in `recording-instructions.md`.
- [ ] No operator names or personal identifiers appear in the files.

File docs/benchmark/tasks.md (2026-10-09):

---
title: How to perform each task
description: Starting states, actions, success criteria, timeouts, and reset instructions for all 13 HiveBoard evaluation conditions.
---

# How to perform each task

Select a task below for its starting state, required actions, success criterion, and reset. Record **five trials for each of the 13 conditions (65 trials total)**. The two ball-valve configurations are separate conditions.

| Task | What to do | Timeout |
|---|---|---:|
| [Ball valve](#ball-valve) | Rotate the handle 90° from closed to open | 60 s |
| [Ball valve + ring](#ball-valve-with-friction-ring) | Perform the same rotation with the ring fitted | 90 s |
| [Gate valve (small)](#small-gate-valve) | Rotate the stem one full turn from closed | 90 s |
| [Gate valve (large)](#large-gate-valve) | Rotate the stem one full turn from closed | 120 s |
| [Circuit breaker](#circuit-breaker) | Move the toggle to the opposite state and hold it | 60 s |
| [Light bulb](#light-bulb-and-socket) | Thread the bulb into the socket until seated | 120 s |
| [Thread (M8)](#m8-threaded-fastener) | Thread the bolt along the available length | 120 s |
| [Thread (M30)](#m30-threaded-fastener) | Thread the bolt along the available length | 120 s |
| [Peg insertion](#threaded-peg-insertion) | Align and thread the free peg into the socket until seated | 120 s |
| [Button](#covered-button) | Open the cover, then press the button until actuation | 60 s |
| [Lock and key](#lock-and-key) | Grasp the key, insert it vertically, and rotate to unlock | 180 s |
| [Drawer](#sliding-drawer) | Grasp the handle, pull open, then push closed | 120 s |
| [Shock absorber](#shock-absorber) | Grasp the loose part, align its hole with the pin, and insert the part fully onto the pin | 180 s |

Task names follow Table 2 of the paper. See [Terminology](/reference/terminology) to match them to trial IDs and older file names.

## Before every trial

Fully seat the attachment and restore the starting state described below. For loose parts, document their starting pose and use the same pose between trials. Where initial thread engagement is part of the setup, document and restore that engagement; this guide does not introduce a new number of starting turns.

Start the end-effector from the same neutral pose for the platform. Record the complete physical trial with an external camera. Start timing with the first commanded task motion; when using the [Evaluation Runner](/benchmark/evaluation-runner), begin that motion when the countdown reaches zero. Stop at success, a safety stop, or the timeout.

For familiarization, outcome labels, and handling broken or displaced parts, follow the [evaluation protocol](/benchmark/protocol). Example videos remain available in the runner.

## Ball valve

Task ID: `valve_ball`

| Step | Instruction |
|---|---|
| Starting state | Handle closed; no friction ring fitted; attachment fully seated. |
| Action | Engage the handle and rotate it 90° toward the open position. |
| Success | The handle reaches the open position after a 90° rotation. |
| Timeout | 60 s. |
| Reset | Return the handle to closed and check attachment seating. |

## Ball valve + ring {#ball-valve-with-friction-ring}

Task ID: `valve_ball_ring`

| Step | Instruction |
|---|---|
| Starting state | Friction ring fitted; handle closed; attachment fully seated. Document which ring is used. |
| Action | Engage the handle and rotate it 90° toward the open position with the ring fitted. |
| Success | The handle reaches the open position after a 90° rotation. |
| Timeout | 90 s. |
| Reset | Keep the same ring fitted, return the handle to closed, and check attachment seating. |

## Gate valve (small) {#small-gate-valve}

Task ID: `valve_gate_small`

| Step | Instruction |
|---|---|
| Starting state | Stem in the closed starting position. Identify its initial orientation so one full turn can be observed. |
| Action | Turn the valve to rotate the stem through one complete revolution from closed. |
| Success | The stem completes one full turn (360°). Full opening travel is not required. |
| Timeout | 90 s. |
| Reset | Reverse the motion to restore the closed starting position and initial orientation. Keep the board position unchanged. |

## Gate valve (large) {#large-gate-valve}

Task ID: `valve_gate_large`

| Step | Instruction |
|---|---|
| Starting state | Stem in the closed starting position. Identify its initial orientation so one full turn can be observed. |
| Action | Turn the valve to rotate the stem through one complete revolution from closed. |
| Success | The stem completes one full turn (360°). Full opening travel is not required. |
| Timeout | 120 s. |
| Reset | Reverse the motion to restore the closed starting position and initial orientation. Keep the board position unchanged. |

## Circuit breaker

Task ID: `circuit_breaker`

| Step | Instruction |
|---|---|
| Starting state | Toggle in the documented initial state. |
| Action | Move the toggle to the opposite state and hold it there. |
| Success | The toggle has changed state and is held in that state. |
| Timeout | 60 s. |
| Reset | Return the toggle to the initial state and check that it moves freely. |

## Light bulb {#light-bulb-and-socket}

Task ID: `light_bulb`

| Step | Instruction |
|---|---|
| Starting state | Bulb removed from the socket and placed in its documented starting pose; thread clear. |
| Action | Align the bulb with the socket and rotate it to engage and advance the thread. |
| Success | The bulb is fully threaded until seated. |
| Timeout | 120 s. |
| Reset | Unscrew and remove the bulb, restore its starting pose, and inspect the thread. |

## Thread (M8) {#m8-threaded-fastener}

Task ID: `thread_m8`

| Step | Instruction |
|---|---|
| Starting state | Bolt at the documented initial thread engagement; thread clear. |
| Action | Rotate the bolt to advance it along the thread. |
| Success | The bolt is fully threaded along the available length. |
| Timeout | 120 s. |
| Reset | Return the bolt to its initial engagement and inspect the thread. |

## Thread (M30) {#m30-threaded-fastener}

Task ID: `thread_m30`

| Step | Instruction |
|---|---|
| Starting state | Bolt at the documented initial thread engagement; thread clear. |
| Action | Rotate the bolt to advance it along the thread. |
| Success | The bolt is fully threaded along the available length. |
| Timeout | 120 s. |
| Reset | Return the bolt to its initial engagement and inspect the thread. |

## Peg insertion {#threaded-peg-insertion}

Task ID: `peg_insertion`

| Step | Instruction |
|---|---|
| Starting state | Socket empty; free 8 mm threaded peg in its documented pose next to the socket. |
| Action | Pick up the peg, align it with the socket, and rotate it to engage and advance the thread. |
| Success | The peg is threaded into the socket until seated. Simply placing it in the opening is insufficient. |
| Timeout | 120 s. |
| Reset | Unscrew and remove the peg, leave the socket empty, and restore the peg's starting pose. |

## Button {#covered-button}

Task ID: `button`

| Step | Instruction |
|---|---|
| Starting state | Cover closed; button returned to its unpressed state. |
| Stage 1 | Open the cover to expose the button. |
| Stage 2 | Press the button until actuation. |
| Success | Both stages complete within the timeout. |
| Timeout | 60 s for the complete sequence. |
| Reset | Release the button, confirm that it returns, and close the cover. |

Record `stage_reached = 0` if no stage completes, `1` if only the cover is opened, or `2` when the button is also actuated.

## Lock and key

Task ID: `lock`

| Step | Instruction |
|---|---|
| Starting state | Lock in its locked initial state; key removed and placed in its documented starting pose. |
| Stage 1 | Grasp the key. |
| Stage 2 | Insert the key vertically into the lock. |
| Stage 3 | Rotate the key to unlock. |
| Success | The lock is unlocked after all three stages. |
| Timeout | 180 s for the complete sequence. |
| Reset | Restore the lock's initial state, remove the key, and return the key to its starting pose. |

Record the last completed stage: `0`, `1`, `2`, or `3`. Inserting the key without unlocking is stage `2`, not full success.

## Drawer {#sliding-drawer}

Task ID: `drawer`

| Step | Instruction |
|---|---|
| Starting state | Drawer fully closed. |
| Stage 1 | Grasp the handle. |
| Stage 2 | Pull the drawer open. |
| Stage 3 | Push the drawer closed again. |
| Success | The drawer has been opened and then closed after grasping the handle. |
| Timeout | 120 s for the complete sequence. |
| Reset | Return the drawer to the fully closed position. |

Record the last completed stage: `0`, `1`, `2`, or `3`. Opening the drawer without closing it is stage `2`, not full success.

## Shock absorber

Task ID: `shock_absorber`

**Grasp the loose part of the shock absorber and insert it onto the pin.** The loose part moves while the pin stays in place. The complete sequence has three stages and a single 180 s timeout.

| Step | Instruction |
|---|---|
| Starting state | Loose part removed from the pin and placed in its documented starting pose. Leave the pin in place and check that the attachment is seated in both occupied board cells. |
| Stage 1 — grasp | Approach and grasp the loose part of the shock absorber with the end-effector. |
| Stage 2 — align | Align the hole in the grasped part with the pin. |
| Stage 3 — insert | Move the aligned part onto the pin until it is fully inserted. |
| Success | All three stages are complete, with the loose part fully inserted onto the pin. |
| Timeout | 180 s total, beginning with the first commanded task motion. Do not restart the timer between stages. |
| Reset | Remove the loose part from the pin and return it to its starting pose. Leave the pin in place and check attachment seating in both board cells. Restore the end-effector's neutral pose before the next trial. |

Record the last **completed** stage:

| `stage_reached` | What was completed |
|---|---|
| `0` | The loose part was not grasped. |
| `1` | The loose part was grasped, but alignment with the pin was not completed. |
| `2` | The hole in the part was aligned with the pin, but the part was not fully inserted onto it. This includes partial insertion. |
| `3` | The part was fully inserted onto the pin. |

For example, if the part is aligned but only partly inserted onto the pin when 180 s expires, record `outcome = timeout`, `stage_reached = 2`, and leave `completion_time_s` blank. Also record attempts, regrasps, strategy, and the dominant failure cause. See [trial logging](/benchmark/logging) for the field definitions.

See the [source protocol](https://github.com/hiveboard-bench/HiveBoard/blob/main/Documentation/PROTOCOL.md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) for success criteria and timeouts. The protocol does not specify a numeric insertion depth, holding duration, or loose-part pose. Document the starting pose and use the same setup for every trial.

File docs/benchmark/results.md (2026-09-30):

# Report results

Report performance per condition and preserve the trial-level data. Aggregate values alone hide the failure modes and stage progression that make the benchmark informative.

## Recommended metrics

| Metric | Calculation | Report for |
|---|---|---|
| Success rate | Successful trials ÷ recorded trials | Every condition |
| Completion time | Median and individual successful-trial times | Every condition with successes |
| Attempts | Median and individual counts | Every condition |
| Regrasps | Median and individual counts | Every condition |
| Stage completion | Fraction reaching each stage | Composed assembly tasks |
| Failure distribution | Count by dominant failure cause | Unsuccessful trials |
| Strategy distribution | Count of prehensile and non-prehensile trials | Every condition |

With five trials per condition, always show the numerator and denominator—for example, `4/5 (80%)`—rather than only a percentage.

Use the [counting conventions](/benchmark/logging#counting-conventions) for attempts and regrasps. If an existing dataset reports total grasps, retain that label until its counting convention has been checked. Do not relabel grasp counts as regrasp counts.

## Keep conditions separate

Do not merge results across:

- different end-effectors;
- different control interfaces or policies;
- horizontal and vertical board mounting;
- ball valve trials with and without the friction ring;
- materially different print settings or modified parts; or
- simulation and physical trials.

## Accompanying files

A complete submission contains 65 trials: five for each of the 13 conditions. Include these files:

```text
result-package/
├── trials.csv
├── setup.jpg
├── platform.md
├── manifest.json
├── session.json
├── recording-instructions.md
└── videos/              # one recording per trial
```

The platform description identifies the robot, end-effector, control interface, board orientation, calibration notes, HiveBoard version, printing parameters, post-processing, and any protocol deviations.

The [Evaluation Runner](/benchmark/evaluation-runner) generates the ZIP after all 65 trial entries and required setup details pass validation. Attach a JPEG setup photograph to include it as `setup.jpg`, or add it after extracting the ZIP. Add the recordings to `videos/` using the filenames in the generated recording instructions.

### Find `recording-instructions.md` {#recording-instructions}

The runner creates **`recording-instructions.md` inside your results ZIP**. Its contents depend on your evaluation session, so there is no separate file to download from GitHub or the documentation website.

1. Complete the required setup details and all 65 trial records.
2. Open **Review** in the Evaluation Runner and select **Download results (.zip)**.
3. Extract the ZIP and open the folder named with your submission ID.
4. Open `recording-instructions.md`, beside `trials.csv` and `platform.md`. Any text editor can read this Markdown file.
5. Use its trial-by-trial filename table to rename your recordings and place them in the `videos/` folder.

Record each trial during the evaluation. For physical trials, start an external camera before the countdown and keep the board, robot, end-effector, and final task state visible throughout. For simulated trials, record the complete trial on screen. Keep one MP4 per trial and track which trial it belongs to. Rename the files after downloading the results ZIP.

| Runner download | Contents | Includes `recording-instructions.md`? |
|---|---|---|
| **Download results (.zip)** | Trial records, platform description, manifest, session backup, and recording and submission instructions | Yes, inside the extracted submission folder |
| **Download trials.csv** | Trial log only | No |
| **Export session** | JSON backup for resuming the evaluation | No |

“Trial records complete” refers to the log and setup fields. It does not confirm that all supporting files are present or that an organizer has reviewed the outcomes. The manifest lists the expected recordings and whether the setup photograph was included when the ZIP was generated.

### Learning data collected during evaluation

If you recorded the trials with [DataHive](/guides/datahive), keep an index linking the benchmark trial IDs to the learning episodes and submit the dataset through the [dataset call](/contribute/evaluations#send-the-data-for-review). DataHive's extended annotation CSV does not replace the benchmark `trials.csv` in this package. Enter the scored results in the website Evaluation Runner to generate the submission ZIP; see the [combined workflow](/guides/datahive#collect-during-a-benchmark-evaluation).

## Submit for organizer review

Submissions are reviewed by email. There is no upload server or automatic approval.

1. Complete all 65 trial entries and the required platform details in the [Evaluation Runner](/benchmark/evaluation-runner).
2. In **Review**, select **Download results (.zip)** and extract it. Open `recording-instructions.md` inside the extracted submission folder. Add `setup.jpg` if it is not already included, and place the 65 external-camera recordings in `videos/` using the listed filenames. For simulated evaluations, provide screen recordings of the complete trials.
3. Recompress the completed folder and upload it to storage you control. Give **ricardo.godoy@usp.br** download access and keep the package private during review. Keep the link available until review is complete.
4. In the runner's Review step, select **Submit for review**. Enter your contact name, email, institution (or Independent), and the package link. Robot, end-effector, and control interface are taken from the evaluation setup.
5. Confirm file completeness and permission to publish the approved trial data, platform description, setup photograph, and recordings. You must have permission to share the materials, including permission from identifiable people in the media.
6. Select **Prepare submission email**, review the draft, and send it from your email application. If no email application opens, copy the draft and send it to **ricardo.godoy@usp.br**. Opening a draft does not send it or confirm receipt.

Contact details and the private package link are included only in the email draft, not in the exported results or session backups. They must be entered again after reloading the page. Results can still be downloaded without submitting or granting publication permission.

### Organizer review

The organizer checks the 13 conditions and five records per condition, platform metadata, photograph, recording filenames, and the recorded outcomes against the video evidence. Browser validation is a preliminary check; it does not replace this review.

Corrections are requested by email. Keep the same submission ID when supplying a corrected package and describe the changes. Publication follows approval and requires the submitter's recorded permission.

Before publishing, prepare a separate copy containing only the approved trial data, platform description, photograph, and recordings. Check free-text notes and media for personal information. Do not publish contact details, private download links, correspondence, or the organizer's review notes. Public result pages and rankings will be added separately.

## Interpretation

HiveBoard exposes different constraints across attachments. A low score can indicate incompatible grasp geometry, insufficient force, kinematic limits, perception difficulty, slip, or insufficient control precision. Report these causes instead of interpreting every unsuccessful trial as the same type of failure.

Comparisons between platforms should state which factors differ. The protocol characterizes the complete manipulation platform and should not be used to attribute a result to the gripper, robot, controller, or operator in isolation without a controlled experiment.

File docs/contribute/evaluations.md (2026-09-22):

---
description: Contribute HiveBoard manipulation datasets with robot states, actions, camera observations, and task outcomes for learning-based methods.
---

# Open call: datasets for learning-based manipulation

We invite laboratories and individual researchers to collect and contribute **HiveBoard manipulation datasets for training and evaluating learning-based methods**. We seek demonstrations and robot rollouts containing camera observations, robot states, executed control commands, and task outcomes. These data can support imitation learning, visuomotor policy learning, and learning from both successful and unsuccessful attempts.

Robot grippers, dexterous hands, teleoperated and autonomous manipulators, and prosthetic hands are welcome. Physical and simulated evaluations must be identified and submitted separately.

**There is no fixed episode count or requirement to cover all 13 conditions for this call.** Larger collections are encouraged. Contributors can focus on an agreed subset of tasks and collect as many useful demonstrations and rollouts as possible. Include unsuccessful attempts as well as successes, and report the number of episodes per condition. A high success rate is not a requirement for contributing data.

We seek learning data with the robot and sensor streams described below. A formal benchmark evaluation is optional and can accompany the dataset as a separate submission.

We recommend [DataHive](/guides/datahive) to collect, annotate, validate, and upload episodes. Labs already running a benchmark evaluation are encouraged to record the corresponding states, commands, and camera streams for a dataset contribution.

## Before starting

Read the [evaluation protocol](/benchmark/protocol) and [task definitions](/hardware/modules). If you need to print the board, start with the [printing](/hardware/printing) and [assembly](/hardware/assembly) guides.

**Contact [ricardo.godoy@usp.br](mailto:ricardo.godoy@usp.br?subject=HiveBoard%20learning%20dataset%20contribution) before collection** to agree on the tasks, recorded signals, synchronization, file formats, and intended data reuse. Include your robot, end-effector, control interface, cameras and other sensors, board orientation, and whether the data are physical or simulated. Discuss unavailable signals or modified mechanisms at this stage.

## Collect with DataHive

Follow the [DataHive guide](/guides/datahive) to install the toolkit, define the robot and camera profile, and prepare a recording integration (see [`fr3_datahive`](https://github.com/hiveboard-bench/fr3_datahive) for a Franka Research 3 reference setup). Its local Runner supports manual collection with attached episode files or automatic collection through the lab's robot script. The Annotate page and command-line tools support episode review and validation.

To contribute episodes with DataHive, register your laboratory through the [DataHive Lab Registration Form](https://docs.google.com/forms/d/e/1FAIpQLScfDJvfcweYjv8bLDEALWOJk1q4mW3xOeB52aUey1VWWp_pxQ/viewform?usp=dialog) to receive your assigned `lab_id` and Hugging Face authentication token.

DataHive stores states and commands in HDF5, camera recordings in MP4, and task annotations in a session CSV. Validated episodes are uploaded directly to your private Hugging Face dataset repository (`HiveBoard/<lab_id>`) via `datahive upload` or `datahive sync`. See the [DataHive guide](/guides/datahive#upload-to-hugging-face-hub) for the complete workflow. Check the [current acquisition requirements](/guides/datahive#check-the-recording-setup-first) and validate a pilot episode before collecting the full dataset. Depth, force/torque, tactile, and other additional streams remain welcome; agree on supplemental formats for signals outside the toolkit's current episode format.

DataHive is the recommended collection workflow, not a requirement for acceptance. Existing datasets and other documented recording formats can be discussed with the organizers.

## Data to record

Record the streams at their native acquisition rates and provide timestamps so observations, measured states, and issued commands can be aligned. State which signals are measured, estimated, or commanded. Preserve the raw data and document any filtering or resampling in derived files.

| Data | What to include |
|---|---|
| Robot states | Joint positions and velocities, end-effector pose, and gripper opening or hand joint states. Include measured effort, torque, or motor current where available. Specify joint order, units, and coordinate frames. |
| Actions and commands | The commands actually sent to the robot or controller, their timestamps, and control mode. State whether actions are joint targets, Cartesian targets or increments, velocities, torques, or gripper commands. Include scaling, limits, and the command frame. |
| Camera observations | Timestamped RGB streams from wrist-mounted and external cameras used during collection. Include depth when available, with its units, scale, invalid-value convention, and RGB alignment. Document image resolution and encoding. |
| Other sensors | Force/torque, tactile, proprioceptive, or interface signals where available, with channel definitions, units, and timestamps. For prosthetic systems, describe the recorded hand states and input signals. |
| Timing and calibration | Sampling rates, clock sources, timestamp meaning, synchronization method, known offsets or delays, and dropped samples. Include camera intrinsics, distortion parameters, extrinsics, and frame transforms used to interpret the observations. |
| Episode metadata | Episode ID, task/condition ID, platform configuration, asset version, initial state, start/end boundaries, outcome, failure cause, and correspondence with the benchmark trial record where applicable. Label resets, interventions, and aborted episodes. |

For simulation, also record the simulator and asset versions, physics settings, seeds, and any randomization used. Identify privileged simulator state separately from the observations available to a policy.

The baseline is camera observations, robot states, and timestamped actions. Additional sensing is welcome. If your platform cannot expose a baseline signal, discuss the limitation with the organizers before collection. Do not infer control commands from measured motion and present them as recorded actions.

## Collect the episodes

1. Document the platform configuration, HiveBoard version, board orientation, printing settings, and any post-processing or protocol deviations.
2. Define the tasks, initial states, reset procedures, and episode boundaries. Identify changes in platform configuration, control interface, or task difficulty in the metadata.
3. Collect demonstrations or robot rollouts with synchronized observations, states, and commands. Larger datasets and variation in starting states, viewpoints, operators, and strategies are welcome; document the variation used.
4. Preserve successes, failures, timeouts, interventions, and aborted episodes, and label them accurately. Distinguish the ball-valve configurations and other task variants.
5. Record task outcomes and failure causes for each episode. Where applicable, use the stage, attempt, and regrasp definitions in the [logging instructions](/benchmark/logging).

Identify the demonstration source or policy used for each episode and any data used to train or tune it. Preserve session boundaries so related trajectories can be grouped when constructing training and test splits. If you also report benchmark performance, keep those scored trials separate from training data.

**Record physical episodes with an external camera**, keeping the board, end-effector, and relevant task state visible. Record the complete episode without cuts and align the video with the episode timestamps. For simulated data, include rendered observations and a way to inspect task execution.

## Required submission

| Material | Requirement |
|---|---|
| Episode records | One entry per episode with condition, outcome, duration, data-file references, and counts summarized per task |
| Platform description | `platform.md` identifying the robot, end-effector, control interface, evaluation mode, mounting, and relevant setup details |
| Setup image | `setup.jpg` showing the experimental setup; use a view of the simulated setup for simulation |
| Recordings | External-camera video for physical episodes and rendered observations for simulation, mapped to episode IDs and timestamps |
| Learning data | Timestamped robot states, actions, camera streams, and other recorded sensors, grouped into episodes |
| Dataset documentation | Signal definitions, units, frames, rates, synchronization and calibration details, missing signals, collection procedure, and data reuse terms |
| Episode index and reader | An index mapping learning-data episodes to trial IDs, task conditions, outcomes, and files; a script or notebook that loads an episode and aligns observations, states, and actions |
| Contact and permission | Contact name, email, institution or Independent, package link, and proposed data reuse and publication terms, supplied by email |

**Connect DataHive to your experimental system or use an agreed recording format.** The website Evaluation Runner records benchmark outcomes and timing; it does not acquire robot telemetry, camera streams, or control commands. DataHive's local Runner is a separate tool for collecting and annotating learning episodes.

ROS bags, HDF5, Zarr, or an existing documented learning-dataset format can be discussed with the organizers. Include a small loading example with dependency versions. Video plus a trial CSV alone is insufficient for the learning-data call.

Organize the learning data, calibration, episode index, reader, setup description, and dataset README in a documented folder or archive. If the data are too large for one archive, use a shared folder with a file index and checksums covering all data shards.
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

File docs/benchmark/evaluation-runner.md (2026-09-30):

---
aside: false
pageClass: runner-page
title: Evaluation Runner
description: Run HiveBoard trials and export a protocol-compatible CSV in the browser.
---

<script setup>
import EvaluationRunner from '../.vitepress/theme/components/EvaluationRunner.vue'
</script>

# Evaluation Runner

Record HiveBoard trials using the timer and trial form below. Select a condition, review its success criterion, and start the countdown. Begin the task when the countdown reaches zero. After each trial, enter the outcome, attempts, and regrasps. The evaluator determines success; the runner records time and stops at the task timeout.
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

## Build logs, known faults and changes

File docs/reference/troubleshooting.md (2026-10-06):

# Troubleshooting

## An attachment does not fit

Print one cell and one attachment base using the same material and profile. Check for elephant's foot, warping, or excess material before modifying the CAD. If sanding is required, apply it consistently and record it.

## A threaded component binds

Remove stringing and debris, then test the matching calibration piece. Keep the part aligned with the thread axis and do not force initial engagement. Record sanding or lubrication because either can change task resistance.

## An attachment moves during a trial {#a-module-moves-during-a-trial}

Stop if continuation is unsafe. Preserve the trial result, describe the displacement in `notes`, and reseat the attachment before continuing. For repeated release, verify cell tolerances and mounting orientation.

## A printed part breaks

Record the trial as it occurred. Photograph the damage when useful, replace the component with the same print profile, and note the replacement. Do not substitute an unreported rerun.

## Completion time appears as a date

Format the spreadsheet column as a plain number and enter decimal seconds without units. Use `12.9`, not `12.9 s` or a clock value.

## Failed trials have no time

This is expected. `completion_time_s` is only populated for successful trials. Use `outcome=timeout` for a trial that reaches the time limit.

## Simulation geometry loads at the wrong scale

Verify the asset units and the loader's unit conversion. Check both visual and collision geometry before changing the global scene scale.

## A simulation joint moves in the wrong direction

Inspect the joint axis, parent-child order, and initial pose. Compare the full motion with the physical mechanism, not only the rendered rest configuration.

## Simulation contact is unstable

Begin with one environment and a conservative timestep. Inspect collision geometry, penetration at reset, solver settings, drive gains, and mass ratios. The supplied physical properties are nominal. Identify them for the printed mechanism when studying sim-to-real correspondence.

## An Isaac Lab asset cannot be found

The simulation repository uses Git submodules. From the repository root, initialize or update them with:

```bash
git submodule update --init --recursive
```

This initializes the pinned dependencies, including HiveBoard assets, Isaac Lab, cuRobo, and the DynaArm description. Newton USD files also need to be generated locally. Check them with:

```bash
uv run python scripts/generate_newton_usd.py --verify-only
```

Follow the [asset-generation instructions](/simulation/isaac-lab#generate-the-newton-assets) to create missing files. ANYmal has an additional robot-assembly generator. The `--skip-conversion` option cannot replace conversion on a fresh clone.

## An Isaac Lab task is not registered

List all registered tasks without launching the simulator:

```bash
uv run python scripts/record_all_envs.py --all --list
```

Use the exact `Isaac-HiveBoard-*` identifier printed by the script. Robot tokens are case-sensitive, including `Anymal`. Light-bulb tasks provide both `Lamp-v0` and `Lamp-Play-v0` variants for Spot, Franka, and ANYmal. The current Franka ball-valve task uses `Franka-BallValve`, replacing the earlier `Franka-LeverValve` identifier.

If imports fail after updating the repository, run `git submodule update --init --recursive` and `uv sync --python 3.12` from its root. Continue using `uv run` for subsequent commands.

## The command editor does not open in the browser

Start the editor with an explicit port, for example `uv run python scripts/command_edit.py --port 9080`, and open `http://localhost:9080` on the computer running it. Use the address printed by the editor if a different port was selected. See [command editing](/simulation/workflows#edit-a-task-s-command-sequence) for the complete workflow.

## A simulation recording is missing

For batch recording, check `summary.json` and the per-task logs under `videos/environments/<timestamp>/`. Confirm that `ffmpeg` and `ffprobe` are on `PATH`. The default batch selection includes only `-Play` environments, including light bulb. Use `--task` to select one task explicitly, or `--all` to include all variants. See [batch recording](/simulation/workflows#record-several-environments).

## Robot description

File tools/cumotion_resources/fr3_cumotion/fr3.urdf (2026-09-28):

<?xml version="1.0"?>
<robot name="fr3">

  <link name="base_link"/>

  <link name="fr3_link0"/>
  <joint name="base_link_fr3" type="fixed">
    <parent link="base_link"/>
    <child link="fr3_link0"/>
    <origin xyz="0 0 0" rpy="0 0 0"/>
  </joint>

  <link name="fr3_link1"/>
  <joint name="fr3_joint1" type="revolute">
    <parent link="fr3_link0"/>
    <child link="fr3_link1"/>
    <origin xyz="0 0 0.333" rpy="0 0 0"/>
    <axis xyz="0 0 1"/>
    <limit lower="-2.7437" upper="2.7437" effort="87" velocity="2.175"/>
  </joint>

  <link name="fr3_link2"/>
  <joint name="fr3_joint2" type="revolute">
    <parent link="fr3_link1"/>
    <child link="fr3_link2"/>
    <origin xyz="0 0 0" rpy="-1.5707963267948966 0 0"/>
    <axis xyz="0 0 1"/>
    <limit lower="-1.7837" upper="1.7837" effort="87" velocity="2.175"/>
  </joint>

  <link name="fr3_link3"/>
  <joint name="fr3_joint3" type="revolute">
    <parent link="fr3_link2"/>
    <child link="fr3_link3"/>
    <origin xyz="0 -0.316 0" rpy="1.5707963267948966 0 0"/>
    <axis xyz="0 0 1"/>
    <limit lower="-2.9007" upper="2.9007" effort="87" velocity="2.175"/>
  </joint>

  <link name="fr3_link4"/>
  <joint name="fr3_joint4" type="revolute">
    <parent link="fr3_link3"/>
    <child link="fr3_link4"/>
    <origin xyz="0.0825 0 0" rpy="1.5707963267948966 0 0"/>
    <axis xyz="0 0 1"/>
    <limit lower="-3.0421" upper="-0.1518" effort="87" velocity="2.175"/>
  </joint>

  <link name="fr3_link5"/>
  <joint name="fr3_joint5" type="revolute">
    <parent link="fr3_link4"/>
    <child link="fr3_link5"/>
    <origin xyz="-0.0825 0.384 0" rpy="-1.5707963267948966 0 0"/>
    <axis xyz="0 0 1"/>
    <limit lower="-2.8065" upper="2.8065" effort="12" velocity="2.61"/>
  </joint>

  <link name="fr3_link6"/>
  <joint name="fr3_joint6" type="revolute">
    <parent link="fr3_link5"/>
    <child link="fr3_link6"/>
    <origin xyz="0 0 0" rpy="1.5707963267948966 0 0"/>
    <axis xyz="0 0 1"/>
    <limit lower="0.5445" upper="4.5169" effort="12" velocity="2.61"/>
  </joint>

  <link name="fr3_link7"/>
  <joint name="fr3_joint7" type="revolute">
    <parent link="fr3_link6"/>
    <child link="fr3_link7"/>
    <origin xyz="0.088 0 0" rpy="1.5707963267948966 0 0"/>
    <axis xyz="0 0 1"/>
    <limit lower="-3.0159" upper="3.0159" effort="12" velocity="2.61"/>
  </joint>

  <!-- FR3 flange / hand mounting -->
  <link name="hand"/>
  <joint name="fr3_hand_joint" type="fixed">
    <parent link="fr3_link7"/>
    <child link="hand"/>
    <origin xyz="0 0 0.107" rpy="0 0 -0.7853981633974483"/>
  </joint>

  <!-- HiveBoard TCP -->
  <link name="tcp"/>
  <joint name="hand_tcp_joint" type="fixed">
    <parent link="hand"/>
    <child link="tcp"/>
    <origin xyz="0 0 0.1034" rpy="0 0 0"/>
  </joint>

</robot>

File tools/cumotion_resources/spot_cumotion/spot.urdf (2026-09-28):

<?xml version="1.0"?>
<robot name="spot_arm">

  <!-- Kinematic description extracted from the supplied spot_arm.xml.
       The MuJoCo freejoint and locomotion joints are intentionally omitted.
       The six Spot Arm joints form the cuMotion c-space.
       The gripper joint is retained as a non-c-space joint. -->

  <link name="base_link"/>

  <link name="arm_link_sh0"/>
  <joint name="arm_sh0" type="revolute">
    <parent link="base_link"/>
    <child link="arm_link_sh0"/>
    <origin xyz="0.292 0 0.188" rpy="0 0 0"/>
    <axis xyz="0 0 1"/>
    <limit lower="-2.61799" upper="3.14159" effort="90" velocity="10"/>
  </joint>

  <link name="arm_link_sh1"/>
  <joint name="arm_sh1" type="revolute">
    <parent link="arm_link_sh0"/>
    <child link="arm_link_sh1"/>
    <origin xyz="0 0 0" rpy="0 0 0"/>
    <axis xyz="0 1 0"/>
    <limit lower="-3.14159" upper="0.523599" effort="90" velocity="10"/>
  </joint>

  <link name="arm_link_hr0"/>
  <joint name="arm_hr0_fixed" type="fixed">
    <parent link="arm_link_sh1"/>
    <child link="arm_link_hr0"/>
    <origin xyz="0 0 0" rpy="0 0 0"/>
  </joint>

  <link name="arm_link_el0"/>
  <joint name="arm_el0" type="revolute">
    <parent link="arm_link_hr0"/>
    <child link="arm_link_el0"/>
    <origin xyz="0.3385 0 0" rpy="0 0 0"/>
    <axis xyz="0 1 0"/>
    <limit lower="0" upper="3.14159" effort="90" velocity="10"/>
  </joint>

  <link name="arm_link_el1"/>
  <joint name="arm_el1" type="revolute">
    <parent link="arm_link_el0"/>
    <child link="arm_link_el1"/>
    <origin xyz="0.4033 0 0.075" rpy="0 0 0"/>
    <axis xyz="1 0 0"/>
    <limit lower="-2.79253" upper="2.79253" effort="23" velocity="10"/>
  </joint>

  <link name="arm_link_wr0"/>
  <joint name="arm_wr0" type="revolute">
    <parent link="arm_link_el1"/>
    <child link="arm_link_wr0"/>
    <origin xyz="0 0 0" rpy="0 0 0"/>
    <axis xyz="0 1 0"/>
    <limit lower="-1.8326" upper="1.8326" effort="23" velocity="10"/>
  </joint>

  <link name="arm_link_wr1"/>
  <joint name="arm_wr1" type="revolute">
    <parent link="arm_link_wr0"/>
    <child link="arm_link_wr1"/>
    <origin xyz="0 0 0" rpy="0 0 0"/>
    <axis xyz="1 0 0"/>
    <limit lower="-2.87979" upper="2.87979" effort="23" velocity="10"/>
  </joint>

  <link name="arm_link_fngr"/>
  <joint name="arm_f1x" type="revolute">
    <parent link="arm_link_wr1"/>
    <child link="arm_link_fngr"/>
    <origin xyz="0.11745 0 0.01482" rpy="0 0 0"/>
    <axis xyz="0 1 0"/>
    <limit lower="-1.57" upper="0" effort="11" velocity="10"/>
  </joint>

</robot>

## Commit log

2026-08-26 Add project documentation, .gitignore, and source files
    [Ball_Valve_Assembly.stl, Ball_Valve_Base.stl, Ball_Valve_Friction_Ring_Set.stl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]
2026-08-31 feat(sim): add joint-level trajectory editor
2026-08-31 feat(sim): add Macao hand and robot model assets
    [0_base_alma_mesh.obj, 1000_dynaarm_interface_parts.obj, 100_shoulder_mesh.obj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]
2026-09-01 feat(sim): trajectory editing, coming-soon module previews, Platform C
    Simulation widget
    - Task picker is a dropdown of the full 13-module HiveBoard set; modules
    without a solved trajectory show a printable STL preview (fixed base grey,
    manipulated part yellow) with a looping "demonstration" motion.
    - Shock absorber renders as its two adjacent-cell assemblies.
    - Preview STLs decimated to match the scene meshes (tools/decimate-preview-parts.py).
    - Per-module preview placement, saved to public/sim/models/module_placement.json
    via the editor server (?edit=1 Placement panel).
    Trajectory editor (?edit=1)
    - Arm-only "draft" flow: pick a coming-soon task, author joint poses from a
    home key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
    [0_base_alma_mesh.obj, 1000_dynaarm_interface_parts.obj, 100_shoulder_mesh.obj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]
2026-09-01 feat(sim): adjust Platform C DynaArm mount position and update simulator assets
2026-09-01 feat(sim): upgrade ANYmal and DynaArm visual materials, meshes, and PBR rendering
    [dynaarm_base_dark.obj, dynaarm_base_metal.obj, dynaarm_elbow_dark.obj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]
2026-09-06 feat: refresh site and expand simulator task assets
    [button-cover_tn__Tampa1_dC_Corpo1_Mesh.obj, button-cover_tn__botao1_dC_Corpo1_Mesh.obj, button-cover_tn__corpo1_dC_Corpo1_Mesh.obj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]
2026-09-06 fix(ui): make the cross-platform switch legible on phones
    The three panel labels cannot share a line on a phone, and wrapping them
    inside the pill left ragged, uneven segments beside the heading. Below the
    tablet breakpoint the heading row stacks and the switch becomes a full-width
    segmented control with equal columns, so each label gets the same box however
    many lines it needs.
    Claude-Session: https://claude.ai/code/session_01JpEa7GZFyoLiooJUMv2Pxt
2026-09-06 fix(ui): stack the cross-platform switch one option per row on phones
    Three equal columns still cramped the labels; below the tablet breakpoint
    each option now gets its own full-width row, left aligned, so none of them
    wraps.
    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
2026-09-06 fix(sim): make the platform swap atomic so the outgoing robot stops flailing
    loadRobot set `robot = entry` and then awaited the trajectory fetch, leaving
    the render loop to run for the length of that fetch against the outgoing
    mjModel/mjData with the incoming robot's arm count, home pose and grip index.
    `task` was likewise never cleared, so the first frames after the new model was
    built indexed the previous robot's qpos into it. Both show up as the robot on
    screen snapping or folding just before the swap lands.
    Park the loop for the duration, fetch before mutating any shared state, drop
    the stale task with the model it belonged to, and free the previous model and
    data instead of leaking one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
2026-09-06 fix(ui): clean up the hero carousel and links on small screens
    On a phone the carousel's neighbouring cards had nowhere to sit: only a faded
    sliver of each reached the screen, the container's edge mask cut through it,
    and their drop shadows pooled against the centre card's. Below 550px the
    carousel now shows a single card -- neighbours clear of the stage, no edge
    mask, a shadow scaled to the smaller card -- with swipe still moving between
    them.
    The four hero links wrapped onto two ragged rows at unequal widths; below the
    tablet breakpoint they stack one per row at a common width.
    Claude-Session: https://claude.ai/code/session_01JpEa7GZF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
2026-09-06 fix(ui): keep both neighbour videos visible on phones, widen the hero links
    Hiding the neighbouring cards below 550px went too far -- the carousel gave no
    sign the other two videos existed. Narrow the centre card instead so each
    neighbour peeks in well inside the stage, widen the container's edge fade so
    what runs off dissolves rather than being cut square, and keep the lighter
    shadows.
    The stacked hero links also get more width, at their existing height.
    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
2026-09-06 fix(site): declare and cache-bust the whole favicon set
    The page declared only the SVG icon, so a browser that will not use one falls
    back to probing /favicon.ico -- a URL nothing versions, which is why a stale
    tab icon survives a logo change even though the deployed file is current.
    Declare the .ico and the apple-touch PNG alongside the SVG, and stamp all
    three the way stamp-cache.py already stamped the SVG.
    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
2026-09-06 fix(sim): give ANYmal its livery instead of a uniform grey
    The USD carries ANYmal's colours as texture maps, which the web viewer never
    loads, so the conversion assigned two flat greys to the whole robot and the
    arm fell back to a third. Every geom read grey on the page.
    Replace the per-geom rgba with a named palette: a light shell over a charcoal
    frame, red hip housings, black rubber feet, an off-white DynaArm with darker
    joint bands, and a black Robotiq. The names are also load-bearing --
    hiveboard-sim.html picks roughness, metalness and clearcoat out of the material
    name, keying on "shell", "dark" and "metal", which a bare rgba never reached.
    Applied to the committed anymal.xml and to t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
2026-09-06 fix(tools): stop the editor emitting NaN, which no browser can parse
    /manual built its task from a brand-new MjData, and manual_solve only ran a
    forward pass when the board had a spin joint. Without one, xanchor and xaxis
    are still zero, unit() divides by zero, and the task's goal comes out NaN.
    json.dumps writes that as the bare token `NaN` -- legal Python, rejected by
    JSON.parse -- so the whole response was unreadable and the editor could only
    report the status. Forward the data unconditionally and build the task from it.
    The same NaN had already been published: anymal.traj.json carried
    "goal":NaN, so JSON.parse refused the file outright and ANYmal could not load
    in the viewer at all. Rep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
2026-09-06 feat(sim): publish ANYmal without its draft trajectories, and open it up
    The three draft paths never passed contact replay, so they are no longer
    published: anymal.traj.json is empty and the catalogue advertises no tasks.
    With nothing misleading left to show, ANYmal comes out from behind the
    coming-soon gate on the public page -- the platform can be selected and the
    robot inspected against the board. The readout says so when a platform has no
    verified trajectory rather than inviting a task pick.
    The scene, meshes and the editor's manual keys are untouched, so the
    trajectories can be reauthored and republished from the editor.
    Claude-Ses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
2026-09-06 fix(sim): let ANYmal collide with the board, and make its red visible
    Two problems with the same robot.
    Collision: the converter gave every ANYmal collision geom contype 2, which is
    the mask the HiveBoard modules use. MuJoCo pairs geoms when
    (contype1 & conaffinity2) or (contype2 & conaffinity1), and 2 & 1 is 0 both
    ways -- so the arm and gripper passed straight through the breaker, the board
    and everything else. fr3 and Spot carry contype 1, which pairs with the
    modules' conaffinity 1. ANYmal now does too: 38 geoms repaired, contacts at
    rest go from 0 to 5.
    Livery: red reached only the four hip caps, which sit half hidden between body
    and legs, so the robot still read as grey. The thigh s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
2026-09-06 feat(sim): ANYmal runs the valve, lamp and breaker, all three verified
    Now that its geoms actually collide with the board, the three tasks solve
    against the real scene rather than being replayed drafts:
    valve 611 samples, ik error 0.2 mm, lever through its full -1.50 rad
    lamp 886 samples, ik error 1.9 mm, lifts 42.6 mm against a 33.8 mm goal
    breaker 401 samples, ik error 0.2 mm, toggle to +0.46 of +0.46 rad
    The breaker needed the board 2 cm further out (0.80 -> 0.82): at 0.80 the
    fingertips stopped 7 mm short, and moving it closer made that worse, not
    better. The valve and lamp are unaffected by the move. Config and scene are
    changed together so the solver plans against the g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
2026-09-06 fix(sim): repaint ANYmal from the photographs of the real platform
    My palette was guesswork and had it backwards: an off-white arm over a grey
    body, with red on the legs. assets-src/anymal.png and the task posters show the
    opposite -- a red body shell with a black carbon DynaArm, light grey hip
    actuators, and a near-black frame, feet and gripper.
    Colours are now sampled from those images (body 0.76 0.13 0.14, carbon
    0.10 0.09 0.09, hips 0.78 0.78 0.80), and the red goes on the three large base
    covers rather than the legs: 000, 006 and 013 are the body-sized meshes,
    0.8-1.0 m across, against the 0.19 m cubes that are the hip actuators.
    C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
2026-09-06 fix(sim): darken ANYmal's thighs to match the platform
    The legs were the one part no image in the repo shows -- every ANYmal poster is
    a first-person shot that crops them, and the local videos are the printer
    clips -- so the stock light-grey ANYmal-D leg was a guess. It was wrong: the
    thighs are dark like the shanks, with only the hip actuators light grey.
    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
2026-09-06 feat(sim): throw ANYmal's breaker against live collision, not as a demo
    The breaker was published with demo: true, so the toggle replayed an authored
    motion and the module's collision was switched off during playback -- the arm
    never touched it. FR3 opts out with "physical": ["breaker"] and Spot with
    "scripted": False; ANYmal's config, inherited from main, had neither. It now
    carries the FR3's flag, so the module stays collidable and moves only as far as
    the gripper actually pushes it.
    The sweep also had to press 36 mm deeper. With the 2F-140 closed, the fingertips
    sit that far behind the tool point along this approach: measured over the whole
    path, the gripper came no closer than 36.4 mm t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
2026-09-06 fix(sim): stop ANYmal colliding with itself, so the breaker actually throws
    My earlier collision fix gave every ANYmal geom contype 1 with conaffinity 1,
    which pairs a robot geom with the modules -- and with every other robot geom.
    This assembly carries no contact exclusions (main's note that "self collisions
    are disabled" was that blanket contype 2 doing it), so the arm jammed on itself:
    1365 contacts between dynaarm_base and dynaarm_upperarm, another 402 between
    each inner knuckle and the gripper base, and 0.892 rad of joint tracking error.
    The gripper never got within 224 mm of the lever in the physics rollout, which
    is why the toggle only twitched to +0.03.
    conaffinity 2 separates the t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
2026-09-06 fix(sim): fold the saved ANYmal camera views into the published trajectories
    taskView() prefers savedViews[robot][task], but loadSavedViews() returns
    straight away unless PLACE_EDIT is set, so those views only ever reach the
    editor. The page falls back to task.view in the trajectory, and the ANYmal
    trajectories carried none -- hence a different camera on each.
    tools/apply-views.py folds the three saved views in without re-solving. Also
    commits the editor's saved state: the views themselves, and the per-task edits
    it applies live.
    Those edits are still not published -- the shipped paths are the unedited
    solves -- so the editor will keep showing different motion until they are
    saved through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
2026-09-19 Clarify attachment counts, insertion criterion and trial counting
2026-09-26 (feat) Implemented cumotion for spot & FR3 works in parallel with ik solving for cartesian path
    [fr3.urdf, spot.urdf]
2026-09-26 Document ArUco cell printing and board localization
2026-09-28 Restore ANYmal animations and stabilize robot catalogue
    [fr3.urdf, spot.urdf]
2026-09-30 Correct shock absorber task: insert loose part onto pin
2026-10-06 Update simulation documentation for Newton and current task workflows
2026-10-09 Atualiza site e simulação
    Inclui conteúdo e arquivos locais.
    [finger_base.obj, finger_distal.obj, finger_distal_pad.obj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]
2026-10-12 Clarify nut starting states and include initial grasp in trial timing
2026-10-12 Define drawer task as grasping, aligning, and full insertion
2026-10-15 Add cumotion support for new robots: so101, anymal, and macao
    - Introduced URDF and XRDF files for the so101 robot, defining its kinematic structure and joint configurations.
    - Added URDF and XRDF files for the anymal robot, detailing its DynaArm configuration.
    - Created URDF and XRDF files for the macao robot, specifying its floating platform and joint limits.
    - Updated the build-sim-assets script to include new planner configurations for so101, anymal, and macao.
    - Enhanced cumotion planner to recognize and utilize the new robot configurations, including joint names and home positions.
    - Adjusted existing robot configurations to ensure compatibility with the new cumotion framework.
2026-10-15 fix: Fixed gripper preview placement when selecting a key in edit trajectory mode
2026-10-15 Update shock absorber model and related assets
    - Fixed Gripper Preview offset in some keys
    - Adjusted position and orientation of the shock absorber in spot.xml.
    - Updated shock absorber assembly in build-sim-assets.py to correct alignment issues.
    - Added new task for shock absorber compression in sim_trajectories.py. (WIP)
    - Removed outdated shock absorber view from task_views.json.
    - Refined trajectory edits for button-cover and drawer tasks in traj_edits.json.
    - Cleaned up unnecessary entries and improved organization in trajectory edits.
2026-10-15 feat: Completed FR3 Reference arm tasks
2026-10-15 chore: Spot Traj for Small and Large Gate Valves. Also fixing a bug for angle editing in Manual edit mode
2026-10-15 fix: Resolve module prefix that was making m30 thread invisible
2026-10-17 Document ArUco ID 1 and the 360-degree ball-valve variant
